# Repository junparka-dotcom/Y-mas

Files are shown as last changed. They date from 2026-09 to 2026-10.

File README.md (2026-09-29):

# Y-mas — 병실 침대 낙상 감지 / 환자 상태 모니터링 플랫폼

낙상을 "감지"하는 것을 넘어 **낙상 전 위험을 예측(pre-fall)** 하고, 같은
센서 인프라 위에 욕창 예방 자세 분류 등 임상 모니터링을 얹는 **풀 베드
솔루션**을 지향하는 프로젝트입니다.

이 저장소는 검증된 v17 Colab 노트북을 **버전 관리 가능한 모듈 구조**로
재구성한 것입니다. 노트북이 곧 코드였던 기존 방식에서 벗어나, 이 래포가
코드의 단일 진실 소스이고 Colab/GPU 환경은 이 래포를 clone 해 학습만
돌리는 실행기 역할을 합니다.

---

## 시스템 개요 (2-Tier)

| 단계 | 역할 | 구성 |
|---|---|---|
| **Tier 1** | 상시 감시 · 무게중심(COG) 편향 감지 | 로드셀 4채널 → HX711 → ESP32, 80Hz |
| **Tier 2** | 정밀 판정 · 낙상 확정 | ToF 카메라 → YOLO11n-pose → depth 3D 리프팅 → **ST-GCN 기반 모델(이 래포)** |
| **Tier 3** | 알림 | 간호 스테이션 앱 (미구현) |

저비용·저연산 센서(Tier 1)가 24시간 감시하다 위험 신호가 잡히면 고연산
비전 AI(Tier 2)가 깨어나 판정하는 구조입니다. 이 래포는 **Tier 2 모델**을
다룹니다.

## 모델 (v17)

- ST-GCN + Adaptive Graph Adjacency + Multi-Scale TCN(커널 3/5/9)
  + Temporal Attention Pooling + Physics Features 10종 + Auxiliary Fall Head
- trainable 약 1.48M 파라미터 (state_dict 총합 1.50M, BN 버퍼 포함)
- 학습: Focal Loss(γ=1.5) + EMA + Mixup + SWA, 도메인 균형 체크포인트 선택
- 데이터: **NTU RGB+D 120 + ETRI-Activity3D** (둘 다 Kinect V2 계열)
- 배포: ONNX opset 18 → TensorRT FP16 (Jetson AGX Orin)

## 저장소 구조

```
ymas/
  skeleton.py    NTU 25관절 정의 / 뼈대 연결 / 클래스·특징 이름 (단일 진실 소스)
  preprocess.py  전처리 불변식 (normalize_seq, physics_features, to_streams ...)
  config.py      Config + 피험자 분할 + 라벨 정의
  dataset.py     캐시 로드/병합, YmasDataset, DataLoader
  model.py       YmasNet, STGCNBlock, FocalLoss, EMA
  train.py       학습 루프 (EMA/SWA/도메인 균형 선택)
  evaluate.py    진단 + 임계값 스윕 + precision 우선 선택 + Holdout
  export.py      ONNX 내보내기
scripts/
  train_baseline.py   학습 진입점 (--config 로 실험 config 지정)
  diagnose_fa.py      오경보 해부 진단 (도메인/피험자/P(Fall) 분포)
  export_onnx.py      체크포인트 → ONNX
configs/
  v17_baseline.yaml   v13 그리드서치 확정 하이퍼파라미터 (재현 베이스라인)
  v18_aug.yaml        augmentation 강화 실험 (일반화 개선)
edge/                 Jetson Tier 2 실시간 추론 (ymas_realtime_ir.py, C++ 브리지, 캘리브레이션)
integration/          Tier 1 ↔ Tier 2 통합 (ymas_integrated.py, tier1_receiver)
firmware/             ESP32 Tier 1 펌웨어 (.ino)
hardware/             레일 플랫폼 CAD (OpenSCAD 소스 + STL + 프린트 가이드)
docs/
  handover.md         프로젝트 인수인계 (맥락 / 확정사항 / 폐기선택지 / 교훈)
  reference/          부품목록·종합정리 PDF (참고자료)
notebooks/
  colab_train.ipynb   Colab 실행 진입점 (git clone → import ymas)
```

## 학습 실행 (Colab / GPU)

```bash
git clone https://github.com/junparka-dotcom/Y-mas.git
cd Y-mas
pip install -r requirements.txt

python scripts/train_baseline.py \
  --ntu  /content/drive/MyDrive/.../ntu_ymas_v15_T64.npz \
  --etri /content/drive/MyDrive/.../etri_ymas_v15_T64.npz \
  --out  /content/drive/MyDrive/.../ckpt/ymas_v17_repro.pt
```

데이터 캐시(`*_v15_T64.npz`)는 Drive 에 보관하며 래포에는 커밋하지 않습니다
(`.gitignore`). 캐시가 있으면 원본 NTU/ETRI zip(수십 GB) 파싱이 불필요합니다.

## 개발 원칙 (인수인계 교훈)

1. **임계값은 precision≥0.95 게이트를 먼저 걸고 그 안에서 recall 최대화.**
   순서를 뒤집으면(“오경보 0 먼저”) 확률 절벽에서 recall 이 붕괴한다
   (실제 v16 에서 0.988 → 0.06).
2. **계산했다고 반영된 게 아니다.** SWA·평가·저장까지 반드시 검증한다.
3. 치수·스펙은 데이터시트/실물로 확인한다 (추측 금지).
4. Python 래퍼가 막히면 검증된 네이티브 경로로 내려간다.
5. **불변식:** `normalize_seq`, `physics_features`, `to_streams`, `pmean/pstd`
   는 학습·추론 코드에서 완전히 동일해야 한다.

자세한 배경은 [`docs/handover.md`](docs/handover.md) 참고.

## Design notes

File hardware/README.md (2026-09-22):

# Y-mas Tier 1 — 레일 플랫폼 CAD 파일

2026-08-18 설계분을 대화 기록에서 복원한 것입니다.

## 복원 검증

원본 생성 당시의 OpenSCAD `echo` 출력과 이번 재생성 출력이 일치합니다.

| 항목 | 원본(2026-08-18) | 현재(개선 반영) |
|---|---|---|
| 패드 | 200x50x6 / 단상 5 | + 하면 4점 지지 발 12x2.5 (전체 Z 13.5) |
| 브래킷→**어댑터** | 90x60x6 | **80x80x12** (PDF 확정치, 로드셀 40mm 대응 오프셋) |
| 램프 세그먼트 | 108.229mm, 0→29→58→87 | **115.694mm, 0→31→62→93** + 다웰 결합 |
| 데크 높이 | 87mm | **93mm** (어댑터 12mm 도입) |
| MCU 박스 | 미복구 | **복원** 80x60x30 (ESP32 55x26x13 실측 반영) |

> **개선 이력:** 계측 안정성/조립성 개선으로 아래가 바뀌었습니다.
> - 패드: 하면 전면접촉 → **4점 지지 발**(바닥 요철에도 영점 안정)
> - 브래킷 → **어댑터 플레이트(80×80×12)**: 로드셀 40mm 대응 + 자유단 체결홀이
>   바퀴 슬롯을 관통하지 않도록 레일 체결점을 오프셋. **오프셋 30mm는 임의값**이라
>   실측 확정 필요(MEASUREMENTS_TODO C). 두께 12mm로 굽힘강성도 확보.
> - 크래들: V홈을 **바퀴 지름 기반 파라메트릭**으로 정리 + 실측 강제 assert
> - 램프: 세그먼트 접합면에 **다웰 핀/구멍**(밀림 방지). 데크 93mm라 세그 115.7mm
> - MCU 박스: `mcu_enclosure.scad` **신규 복원**(base/lid), ESP32 실측 55×26×13 반영
> - 펌웨어: 빈 상태 **자동 영점 보정(auto-tare)**로 PETG 크리프 드리프트 대응

## 포함 파일

### 소스 (.scad) — 치수 수정은 여기서
```
rail_spec.scad             공용 파라미터  ← 실측값은 여기만 고치면 전체 연동
wheel_cradle.scad          바퀴 크래들
rail_loadcell_mount.scad   패드 + 어댑터 (part="pad" / "bracket")
rail_ramp_segment.scad     램프 분할 (seg=0/1/2)
wheel_chock.scad           고임목
mcu_enclosure.scad         중앙 MCU 박스 (part="base" / "lid")
rail_system.scad           전체 조립 뷰 (아래 '미복구' 참고)
```

### 출력용 (.stl)
```
rail_pad.stl          바닥 패드 + 로드셀 고정단 단상        x4
rail_adapter.stl      로드셀 자유단 ↔ 레일 어댑터(80x80x12) x4
wheel_cradle.stl      얕은 V 크래들                         x4
wheel_chock.stl       고임목                                x8
rail_ramp_seg0/1/2    램프 3분할                            각 x2
mcu_box_base.stl      중앙 MCU 박스 본체                    x1
mcu_box_lid.stl       중앙 MCU 박스 뚜껑                    x1
hx711_box_base.stl    HX711 박스 본체                       x4
hx711_box_lid.stl     HX711 박스 뚜껑                       x4
```

## 인클로저 (복원 완료)

`hx711_enclosure.scad` (HX711 박스 34x24x16) / `mcu_enclosure.scad` (MCU 박스
80x60x30, ESP32 55x26x13 실측 반영) **둘 다 복원 완료**. 각각 `part="base"`/`"lid"`.
`rail_system.scad` 전체 조립 뷰도 이제 정상 렌더됩니다(데크 93 / 램프 347 / 레일 2100).

공통 규격: 벽 두께 2~2.5mm, 모서리 필렛 R1.5~2, 볼트+육각너트 트랩 관통 체결.
HX711 박스는 유닛당 1개 = 4개, MCU 박스는 중앙 1개.

## STL 재생성

```bash
openscad -D 'part="pad"'     -o rail_pad.stl      rail_loadcell_mount.scad
openscad -D 'part="bracket"' -o rail_adapter.stl  rail_loadcell_mount.scad
openscad                     -o wheel_cradle.stl  wheel_cradle.scad
openscad                     -o wheel_chock.stl   wheel_chock.scad
for i in 0 1 2; do openscad -D "seg=$i" -o rail_ramp_seg$i.stl rail_ramp_segment.scad; done
openscad -D 'part="base"'    -o mcu_box_base.stl    mcu_enclosure.scad
openscad -D 'part="lid"'     -o mcu_box_lid.stl     mcu_enclosure.scad
openscad -D 'part="base"'    -o hx711_box_base.stl  hx711_enclosure.scad
openscad -D 'part="lid"'     -o hx711_box_lid.stl   hx711_enclosure.scad
```

또는 배치 출력용 plate 재생성: `python3 make_plates.py`

## 실측 후 수정할 파라미터 (rail_spec.scad)

```
wheel_d=60; wheel_thk=22;   // 바퀴 지름/두께 — 캘리퍼스 실측 필수
CASTER_PITCH = 1700;        // 앞뒤 캐스터 간격 — COG_X 계산에 직결
CRADLE_depth = 9;           // V홈 깊이 — 실물 굴림 테스트 필요
```
`rail_system.scad`의 `rail_gap = 560`(좌우 캐스터 간격)도 COG_Y에 직결됩니다.

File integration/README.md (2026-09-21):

# integration/ — Tier 1 ↔ Tier 2 통합

ESP32(Tier 1, 하중/COG) 가 UDP 로 ALERT 를 보내면 Jetson(Tier 2, 비전) 이
`threading.Event` 로 깨어나 낙상을 확정하는 2-Tier 연동.

## 파일

| 파일 | 역할 |
|---|---|
| `ymas_integrated.py` | Tier 1(하중) + Tier 2(비전) 통합 실행. ESP32 UDP 수신 → 인터럽트 → 비전 스레드 → ST-GCN → MQTT 알람. `--sim --mock-camera` 로 하드웨어 없이 테스트 가능 |
| `ymas_tier1_receiver.py` | Tier 1 수신부. ESP32 하중/COG 수신(Serial/UDP) + 모니터링/로깅 + ALERT 시 Tier 2 기동. 시뮬레이터 내장 |
| `collect_ymas_jetson.sh` | Jetson 자산 수집 스크립트 |

## 하드웨어 없이 Tier 1 검증하기 (시뮬레이터)

ESP32·센서·납땜 없이 `ymas_tier1_receiver.py` 의 내장 시뮬레이터(`--sim`)로
Tier 1 로직 전체(3-Path 감지 / 낙상 vs 정상기상 구분 / ALERT → Tier 2 기동)를
검증할 수 있다.

```bash
# 낙상: ALERT 발생 + Tier 2 기상 + 반응시간 측정
python3 ymas_tier1_receiver.py --sim --scenario fall --quiet

# 정상 기상: ALERT 가 뜨지 않아야 정상 (오탐 없음)
python3 ymas_tier1_receiver.py --sim --scenario exit --quiet

# 그 외 시나리오: edge(가장자리 접근), normal(안정)
python3 ymas_tier1_receiver.py --sim --scenario edge
```

### 검증 완료 (2026-09, 시뮬레이터)
- **낙상(fall):** 낙하 개시 → ALERT 까지 **반응 시간 166ms** (사유
  FASTPATH_WEIGHT_DROP). 인수인계 목표 141~181ms 범위 내. Tier 2 기상 시
  인터럽트 직전 200프레임 하중 이력 확보 확인.
- **정상 기상(exit):** ALERT/인터럽트 미발생 → 침대에서 내려가는 동작을
  낙상으로 오탐하지 않음 (낙상 0.6s 급락 vs 정상기상 2.5s 완만 감소를 dW/dt 로 구분).
- **파싱 정합성:** 펌웨어 출력 포맷(YMAS 16필드 / YMAS_ALERT 8필드)과
  수신부 파서 일치 확인.
- 결론: **Tier 1 소프트웨어 로직은 검증 완료.** 남은 것은 실물(ESP32 +
  HX711·로드셀 납땜) 검증 — 하드웨어 준비 후 펌웨어 업로드 → rate(80Hz 확인)
  → tare → calall → 실측.

## [!] 버전 주의 — ymas_integrated.py 는 구버전(v13) 기준

`ymas_integrated.py` 는 헤더가 **ST-GCN v13 / `ymas_v13.onnx`** 기준으로
작성되어 있다. 현재 확정 모델은 **v21**(배포 th=0.77, physics 10)이므로,
end-to-end 통합 실증 전에 아래를 v21 기준으로 맞춰야 한다:
- ONNX 경로 (`ymas_v13.onnx` → `ymas_v21_model_dropout` 기반 ONNX)
- physics 차원 (v13 은 8, v17+ 은 10)
- PMEAN/PSTD, 임계값 (TH_FALL 0.77)

`ymas_tier1_receiver.py` 의 Tier 2 연동 주석은 이미 th_fall=0.77(v21)로
맞춰져 있고, `edge/ymas_realtime_ir.py` 는 physics 10 / 전처리 불변식이
학습 코드와 동일하므로, 통합 시 edge 쪽 전처리·상수를 기준으로 통일 권장.

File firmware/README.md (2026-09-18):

# firmware/ — ESP32 Tier 1 펌웨어

## `ymas_tier1_firmware.ino`

- **타겟:** keyestudio ESP32-WROOM-32D (KS0413)
- **센서:** CAS BCA-100L ×4 → HX711 ×4
- **역할:** 4채널 하중 수집 → COG 산출 → 3-Path 감지 판정 → LAN UDP 로 Jetson 전송

### 저지연 설계 (v2)

1. HX711 **80Hz 모드** — 샘플 간격 100ms → 12.5ms (**RATE 핀 하드웨어 개조 필수**)
2. 중앙값 필터 — 이동평균 대비 지연 절반, 스파이크 제거 우수
3. 예측 감지 — 이탈도 변화율로 임계 도달 전 선행 알람
4. Fast Path — 체중 급락 시 확정 절차 생략
5. LAN UDP 전송 — 전송 지연 1ms 미만

목표 반응 시간: **0.15 ~ 0.30초**

### COG 산출 (플랫폼 저울 원리)

```
COG_X = CASTER_PITCH × (RL+RR)/total
COG_Y = RAIL_GAP    × (FR+RR)/total
```

`CASTER_PITCH`, `RAIL_GAP` 은 실측 미확정 가정값(1700mm / 560mm). 실물 침대
측정 후 펌웨어 상수를 확정해야 COG 정확도가 보장된다.

### 빌드

Arduino IDE 또는 arduino-cli 로 ESP32 보드에 업로드. HX711 라이브러리 필요.
업로드 전 반드시 HX711 4개의 RATE 핀 개조(트레이스 컷 + 15번 핀 VCC 점퍼)를
완료할 것 — 개조 없이는 10Hz 에 묶여 지연이 1.5초대로 올라간다.

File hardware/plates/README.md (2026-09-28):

# H2D 배치 출력용 Plate (재료별 분리)

밤부랩 H2D 베드(**350×320mm**)에 부품을 묶어 배치한 plate입니다.
**재료별로 폴더가 나뉘어** 있어 PETG는 PETG끼리, PLA는 PLA끼리 출력합니다.
각 plate는 **STL + 3MF** 둘 다 제공합니다.

- **3MF 권장** — Bambu Studio 네이티브 포맷. 오브젝트 분리·배치·재료 지정이 STL보다 매끄러움.
- STL도 동일 내용(멀티오브젝트). 다른 슬라이서 호환용.
- 어느 쪽이든 열면 각 부품이 **개별 오브젝트로 인식**되어 재배치·개별 삭제 가능.

## 폴더 구조

```
plates/
├── petg/   ← 하중 경로 부품 (PETG로 출력)
│   ├── plate_pads.stl / .3mf
│   └── plate_adapter_cradle.stl / .3mf
└── pla/    ← 비하중 부품 (PLA로 출력)
    ├── plate_chock_ramp.stl / .3mf
    └── plate_enclosures.stl / .3mf
```

## 구성 (총 28개 부품 → 4판)

### 🔵 PETG — 하중 경로 (`petg/`)

| Plate | 담긴 부품 | 개수 | 풋프린트 |
|---|---|---|---|
| `plate_pads` | rail_pad | 4 | 200×218mm |
| `plate_adapter_cradle` | rail_adapter ×4 + wheel_cradle ×4 | 8 | 282×258mm |

### 🟢 PLA — 비하중 (`pla/`)

| Plate | 담긴 부품 | 개수 | 풋프린트 |
|---|---|---|---|
| `plate_chock_ramp` | wheel_chock ×8 + rail_ramp seg0/1/2 각 ×2 | 14 | 307×234mm |
| `plate_enclosures` | mcu_box(base+lid) + hx711_box(base×4+lid×4) | 10 | 166×120mm |
| `plate_chock_enclosures` | wheel_chock ×8 + mcu_box + hx711_box(×4) | 18 | 214×234mm |

> **`plate_chock_enclosures`** 는 램프를 지금 안 뽑을 때 쓰는 **통합 판**입니다.
> 휠초크 + 전자부 인클로저를 한 번에 출력 (램프 제외). 램프는 부피가 커서
> 나중에 따로 뽑거나 합판/각목 대체. plate_chock_ramp / plate_enclosures 와는
> 부품이 겹치므로 **셋 중 필요한 조합만** 골라 쓰세요.

모든 판이 베드(350×320) 안에 들어가며, 부품 간 겹침 0, 간격 6mm·가장자리 여백 8mm로 배치했습니다.
생성기(`make_plates.py`)가 **재료 혼합을 assert로 차단**하므로 판에 다른 재료가 섞이지 않습니다.

## 재료 분류 근거

| 부품 | 재료 | 이유 |
|---|---|---|
| rail_pad, rail_adapter, wheel_cradle | **PETG** | 침대 하중이 상시 통과하는 하중 경로 — PLA 크리프로 영점 드리프트 |
| wheel_chock | PLA | 측면 걸림 역할, 지속 압축 없음 |
| rail_ramp seg0/1/2 | PLA | 하중 경로와 분리된 독립 부품, 진입 시 순간 하중만 |
| mcu_box, hx711_box | PLA | 전자부 보호용, 하중 없음 |

## 슬라이서 인필 — 판/오브젝트별로 다르게

| Plate | 재료 | 인필 | 벽 | 이유 |
|---|---|---|---|---|
| `plate_pads` | PETG | **60%+** | 5겹 | 하중 경로. 크리프 방지 |
| `plate_adapter_cradle` | PETG | adapter **60%+** / cradle 40% | 5 / 4겹 | 어댑터는 하중 경로, cradle은 바퀴 하중+마찰 |
| `plate_chock_ramp` | PLA | chock 30% / **ramp 10~15%** | 3겹 | 램프는 하중 분리 부품 |
| `plate_enclosures` | PLA | 20~30% | 3겹 | 전자부 보호용 |

## ⚠️ plate_chock_ramp 는 시간이 오래 걸립니다

램프 3종(seg0/1/2 각 2개)은 솔리드 부피가 커서(seg2 하나만 ~580cm³) 전체 출력량의 대부분을 차지합니다. 권장:

- 램프 인필을 **10~15%**로 낮추고 상/하면 3겹 (강도 충분 — 진입 시 순간 하중만)
- 램프는 정밀도가 필요 없는 15° 경사 형상이라 **합판/각목으로 대체 제작**도 가능
- 시제품 검증 단계면 chock만 먼저 뽑고 램프는 나중에

## 재생성

개별 STL(`../stl/`)이 바뀌면 다시 생성:

```bash
cd hardware
python3 make_plates.py     # plates/{petg,pla}/ 에 STL + 3MF 재생성
```

> 3MF 생성에는 `trimesh` + `networkx` 가 필요합니다(`pip install trimesh networkx`).
> 없으면 STL만 생성되고 안내 메시지가 출력됩니다.

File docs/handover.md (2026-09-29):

# Y-mas 프로젝트 인수인계

> 이 문서는 프로젝트 맥락(설계 근거·확정 사항·폐기 선택지·교훈)을 보존한다.
> 새 작업을 시작하기 전에 반드시 읽고, 여기 적힌 확정 사항과 폐기 선택지
> 안에서 논의할 것.

## 프로젝트 정체성

- **Y-mas** — 병실 침대 낙상 감지 시스템. 궁극 목표는 낙상 "감지"가 아니라
  **낙상 전 위험 예측(pre-fall)**, 나아가 침대 환자 상태 모니터링 **풀 베드
  솔루션**.
- 대학 경진대회 출품작 (AI반도체 전공 학부생).

## 시스템 아키텍처

| 단계 | 역할 | 구성 |
|---|---|---|
| Tier 1 | 상시 감시 · COG 편향 감지 | 로드셀 4 → HX711 4 → ESP32, 80Hz, UDP 트리거 |
| Tier 2 | 정밀 판정 | Femto W(ToF) → IR 주입력 → YOLO11n-pose → depth 3D 리프팅 → ST-GCN(v17) |
| Tier 3 | 알림 | 간호 스테이션 앱 (미구현) |

Tier 1 이 UDP 트리거를 보내면 Tier 2 가 `threading.Event` 로 깨어난다.

## 확정 사항 (변경 제안 불필요)

### 하드웨어
- 엣지 보드: **NVIDIA Jetson AGX Orin 64GB 개발자 키트** (재플래시 완료 2026-09-29)
  - JetPack **6.2.3** (Jetson Linux), CUDA **12.6** (nvcc V12.6.68), Docker 29.8.1
  - Jetson 계정 `ymas`, **IP 192.168.0.9** (`ssh ymas@192.168.0.9`) — ESP32 펌웨어 JETSON_IP 와 일치
  - eMMC 57GB(35GB 여유) — Docker/데이터셋 많이 쓰면 M.2 NVMe 추가 필요
  - 기존 Orin Nano Super 8GB 에서 교체. CUDA/메모리/전력이 커서 추론 여유 대폭↑
    (아래 v17 성능 수치는 Nano Super 기준 하한선 — AGX Orin 에서는 더 빠름)
  - ⚠️ 전력: 평소 50W(`nvpmodel -m 3`), 학습/벤치 시만 MAXN(`nvpmodel -m 0` + `jetson_clocks`)
  - ⚠️ PyTorch 는 `pip install torch`(CPU판) 금지 → JetPack 6.2.3용 NVIDIA wheel/컨테이너 사용
  - ⚠️ Ubuntu 24.04 업그레이드 금지(JetPack 6 = 22.04 기준, CUDA/드라이버 깨짐)
  - 상세 재플래시 절차: `docs/jetson_reflash_2026-09-29.md`
- 카메라: Orbbec Femto W (ToF, Depth/IR) — **IR 이 주 입력** (소등 시 RGB 검출 0)
- MCU: ESP32-WROOM-32D
- 로드셀: CAS BCA-100L ×4 (150×35×**40**mm, 100kg, 2mV/V, IP65)
- 증폭: HX711 ×4, SCK 공유 결선, **RATE 핀 개조로 80Hz** (필수)
- 구조: 알루미늄 프로파일 30×60mm 레일 플랫폼

### Tier 2 모델 (v17)
- ST-GCN + Adaptive Graph + Multi-Scale TCN(3/5/9) + Temporal Attention Pool
  + Physics 10종 + Aux Fall Head
- trainable ~1.48M (state_dict 총합 1.50M, BN 버퍼 포함)
- Focal(γ=1.5), EMA(0.9999), Mixup(0.4), SWA, dropout=0.45, aux_weight=0.15,
  label_smooth=0.15
- 성능(문서 기준): th=0.75 에서 Holdout NTU recall 0.976, ETRI 0.988,
  오경보 79건(P39/P40 집중)
- 배포: ONNX opset 18 → TensorRT FP16, 평균 ≈2ms / ≈478 qps
- ONNX I/O: `skeleton[B,9,64,25]`, `physics[B,10]` → `logits[B,3]`

### 카메라 파이프라인
- IR/Depth 동일 물리 센서 공유 → Align 불필요
- `pyorbbecsdk` 는 0 채운 depth 만 반환 → C++ SDK v1.10.37 브릿지로 우회
  (Unix 도메인 소켓 스트리밍)
- zone 4점 캘리브레이션, 복합 판정(zone 이탈 AND tilt≥45° → Fall),
  EMA 스무딩(α=0.4) + 신뢰도 게이트(0.3)

## 폐기된 선택지 (다시 제안 금지)

### 데이터셋 — 전부 도메인 갭으로 실패
| 데이터셋 | 실패 원인 |
|---|---|
| Kaggle UR Fall | Depth 누락 |
| UP-Fall 3D | MediaPipe 33관절 → NTU 25관절 변환 시 성능 붕괴 |
| PKU-MMD v2 | 좌표계 불일치, precision 0.76 → 0.52 |
| FUKinect-Fall | Kinect V1 노이즈 전 백분위 3배, 필터 불가 |

**결론: 같은 센서 계열(Kinect V2 포맷) 데이터만 학습 투입 가능
→ 현재 NTU RGB+D 120 + ETRI-Activity3D 만 사용.**

### 기타 폐기
- 개별 캐스터 유닛 방식 → 레일 플랫폼으로 전환
- Nuitrack / K4A Body Tracking SDK (Femto W 미지원) → YOLO11n-pose + depth 리프팅
- 자탭 나사 → 볼트+육각너트 트랩 관통 체결
- 더 무거운 스켈레톤 모델(2s-AGCN, MS-G3D, CTR-GCN, ST-TR) — 엣지 실시간성 ·
  데이터 규모 대비 과적합 위험

## 뼈아팠던 교훈

1. **임계값은 precision 게이트(≥0.95)를 먼저 걸고 그 안에서 recall 최대화.**
   "오경보 0 먼저" 규칙이 확률 절벽 끝(th=0.95)을 골라 NTU recall 0.988 → 0.06 붕괴.
2. **계산했다고 반영된 게 아니다.** SWA 가중치를 계산만 하고 저장·평가하지
   않은 버그가 로그상 이상 없이 v13~v15 를 통과.
3. **치수는 데이터시트로 확인.** 로드셀 두께 22mm 가정 → 실제 40mm 로 기구 전면 재설계.
4. **Python 래퍼가 막히면 검증된 네이티브 경로로.** pyorbbecsdk → C++ 브릿지.
5. **불변식:** `normalize_seq`, `physics_features`, `to_streams`, `pmean/pstd` 는
   학습·추론에서 완전히 동일해야 한다.

## 데이터 현황 (캐시 실측)

| 캐시 | 샘플 | 클래스 분포 | 피험자 |
|---|---|---|---|
| `ntu_ymas_v15_T64.npz` (495MB) | 27,679 | Normal 20,114 / Risk 6,618 / Fall 947 | 54 |
| `etri_ymas_v15_T64.npz` (125MB) | 7,002 | Normal 5,168 / Risk 0 / Fall 1,834 (전부 A053) | 60 |

병합 34,681 → Train 18,771 / Val 9,803 / Holdout 6,107.

- pmean = [3.3124, 3.1606, 0.3925, 1.1291, 33.0563, 20.9063, 0.4188, 6.1961, 2.4740, 0.1158]
- pstd  = [7.8035, 5.5430, 0.5598, 0.5744, 27.6783, 22.7895, 0.5998, 9.3450, 0.6205, 0.1538]

### 데이터가 드러낸 약점 (개선 실험 표적)
1. **극심한 Fall 불균형** (Fall 2,781 vs Normal 25,282 ≈ 1:9) + 동적 낙상
   궤적(NTU A043)이 947개뿐. ETRI Fall 1,834 는 "쓰러지는 순간이 없는 정적 자세".
2. **Risk 는 NTU 단독** (ETRI 0) → 도메인 지름길 학습 위험.
3. 오경보가 특정 피험자(P39/P40)에 집중 → 하드 네거티브 문제.

## 미해결 상태

1. **실환경 도메인 갭 (가장 큼)** — v17 은 Kinect/NTU 만 학습해 Femto W 노이즈를
   본 적 없음. 정상 자세에서 P(Fall) 0.75~0.80. 근본 해결은 현 파이프라인으로
   **실데이터 수집 후 파인튜닝** (현재 카메라 수집 불가 상태).
2. 실측 미확정 치수 (캐스터 피치 1700mm, 레일 간격 560mm 등 — COG 식 직결 가정값).
3. Femto W USB 끊김 시 220V 재인가 필요 (무인 운용 리스크).
4. 미구현: Tier 3 앱, Tier 1 실물 제작 · end-to-end 통합, 풀 베드 확장.

## 로드맵

- **Phase 0 (완료)** — v17 노트북을 래포 모듈로 재구성 + 재현 베이스라인 확립.
  Holdout NTU recall 0.9762 / ETRI 0.9875 / 오경보 79 재현 성공 (th=0.75).
- **Phase 1 (v18 완료)** — 캐시 기반 정직한 개선 실험.
  - 진단 결과 하드 네거티브 재가중은 폐기(Train non-Fall 16,905개 중
    P(Fall)>=0.75 단 2건 → 재가중 대상 없음, 순수 일반화 실패로 판명).
  - **augmentation 강화(v18)** 채택: 다축 회전(rot_y 0.35 + rot_xz 0.12)
    + 관절 드롭아웃(p=0.3, frac=0.1). 확신 오답(P>=0.90) 18→7건 감소.
  - **배포 임계값 th=0.78 확정**: NTU 동적 낙상 recall 0.9762 완전 유지하며
    Holdout 오경보 79→67 (-15%). th>=0.79 부터 NTU recall 절벽 붕괴.
  - 관련: configs/v18_aug.yaml, scripts/analyze_threshold.py, scripts/diagnose_fa.py
  - **[폐기] 관절 드롭아웃 강도 튜닝 — v18(frac=0.10)이 스위트 스팟으로 확정:**
    - v19 (frac 0.05, 완화): NTU recall 0.9762→0.9643 하락. **드롭아웃 줄이지 말 것.**
    - v20 (frac 0.15, 강화): 최적 오경보 68(v18은 67), NTU recall 유지 th 범위 더
      좁음. v18 대비 개선 없음. **드롭아웃 더 키우지 말 것.**
    - 결론: 양쪽으로 벗어나면 나빠짐 → joint_dropout_frac=0.10 고정. 이 축은 수렴.
    - (configs/v19_finetune.yaml, configs/v20_strong_dropout.yaml, 둘 다 미병합)
- **Phase 1 최종 (v21 채택):** model dropout 0.45→0.50 (특징 레벨 정규화)이
  일반화를 더 밀어 **미답 피험자(P39/P40)의 동적 낙상까지 완벽 감지**.
  - **배포 th=0.77 확정.** Holdout NTU 동적 낙상 recall **1.000**(84/84),
    전체 오경보 70. th 0.70~0.77 구간에서 NTU recall 1.000 유지, 0.78부터 하락.
  - SWA 가 EMA best 를 이겨 채택됨 (정규화 강화로 SWA 가 더 안정적 해에 수렴).
  - v17→v21 개선: NTU 낙상 recall 0.9762→**1.000**, 전체 오경보 79→70.
  - 판정 근거: 낙상 감지 시스템에서 놓친 낙상(FN)이 오경보(FP)보다 치명적 →
    낙상 2개 추가 감지 vs 오경보 3건 증가는 임상적으로 남는 거래.
  - 관련: configs/v21_model_dropout.yaml. 체크포인트 ymas_v21_model_dropout.pt
- **Phase 1 이후 후보** — 관절 드롭아웃·model dropout 축 모두 탐색 완료.
  캐시 고정·데이터 유일(NTU 947 동적 낙상) 상황에서 모델 쪽 여지는 거의 소진.
  진짜 남은 병목은 실데이터(Phase 2, 카메라 필요)와 배포 정비(AGX Orin).
- **Phase 2 (하드웨어 준비 후)** — Femto W 실데이터 수집 → 파인튜닝으로 도메인 갭 해소.
  (현재 카메라 수집 불가 상태라 보류.)

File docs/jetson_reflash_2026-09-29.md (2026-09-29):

# Jetson AGX Orin 재플래시 작업 정리

**작업일:** 2026-09-29
잠겨 있던 Jetson 초기화 → JetPack 6.2.3 설치 → 노트북 파티션 정리

## 1. 작업 요약

이전 사용자가 쓰던 **Jetson AGX Orin 64GB 개발자 키트**가 비밀번호로 잠겨 있어,
듀얼부팅 노트북(Ubuntu 22.04)의 SDK Manager로 OS를 통째로 재설치(재플래시).
플래시 후 CUDA·개발 도구까지 설치, 작업 공간으로 쓰던 옛 Ubuntu 파티션(p8)은
삭제해 Windows D: 드라이브에 합쳤다.

| 항목 | 결과 |
|---|---|
| Jetson 기기 | Jetson AGX Orin 64GB Developer Kit (64GB eMMC 5.1) |
| 설치 소프트웨어 | JetPack 6.2.3 (Jetson Linux), CUDA 12.6 (nvcc V12.6.68) |
| Jetson 계정 | 사용자명 `ymas` (Pre-Config로 플래시 전 지정) |
| **Jetson IP** | **192.168.0.9** (`ssh ymas@192.168.0.9`) |
| 호스트 PC | 듀얼부팅 노트북, Ubuntu 22.04.5 LTS, x86_64, SDK Manager 2.4.1 |

> **ESP32 펌웨어 연동:** `firmware/ymas_tier1_firmware.ino` 의 `JETSON_IP` 를
> 192.168.0.9 로 맞춰 두었다(UDP 5005). 네트워크가 바뀌면 이 값도 함께 갱신할 것.

## 2. 재플래시가 필요했던 이유

Jetson OS 비밀번호는 OS 안(`/etc/shadow`)에 저장되므로, 모르면 OS 재설치가
가장 확실. Recovery 모드에서는 OS 부팅 전 부트롬이 USB로 명령을 받으므로
잠긴 로그인 화면과 무관하게 저장장치 전체를 덮어쓸 수 있다.

## 3. 사전 확인 (노트북, Ubuntu 터미널)

| 항목 | 명령 | 결과 |
|---|---|---|
| Ubuntu 버전 | `lsb_release -a` | 22.04.5 LTS (jammy) |
| CPU 구조 | `uname -m` | x86_64 |
| 여유 공간 | `df -h /` | / 에 61GB 여유 |

> SDK Manager는 Windows/WSL/VM/Mac에서 플래시가 불안정 → **실제 Ubuntu 부팅** 필수.

## 4. 진행 순서

### 4-1. 작업 폴더 준비 (p8 파티션)
마운트 안 된 ext4 파티션(`nvme0n1p8`, 144.9GB)을 SDK Manager 다운로드용으로 사용.
```
sudo mkdir -p /mnt/p8
sudo mount /dev/nvme0n1p8 /mnt/p8
sudo mkdir /mnt/p8/nvidia
sudo chown $USER:$USER /mnt/p8/nvidia
```

### 4-2. SDK Manager 설치
NVIDIA 개발자 사이트에서 Ubuntu(.deb x86_64) 다운로드 후:
```
cd ~/Downloads
sudo apt install ./sdkmanager_*.deb
sdkmanager
```

### 4-3. SDK Manager 설정
| 단계 | 설정 |
|---|---|
| Step 01 Target HW | 기본값 AGX Thor → **Jetson AGX Orin [64GB developer kit version]** 로 변경 |
| Step 01 SDK Version | **JetPack 6.2.3**, Direct Flash (JetPack 7.x는 Thor용이라 해당 없음) |
| Step 01 Additional SDKs | DeepStream, Holoscan **체크 해제** |
| Step 02 경로 | Download: `/mnt/p8/nvidia/sdkm_downloads`, Install: `/mnt/p8/nvidia/nvidia_sdk` |
| Step 02 체크박스 | 약관 동의, "Download now. Install later" 체크 안 함 |
| Flash 창 | OEM Config: **Pre-Config**(사용자명/비번 지정), Storage: **EMMC** |

### 4-4. Recovery 모드 진입 (AGX Orin 개발자 키트)
1. 전원 어댑터 연결한 채, Jetson 끈 상태(전원 LED 꺼짐)
2. USB-C ↔ USB-A 케이블로 노트북과 **직접** 연결 (허브 금지)
3. **Force Recovery 버튼(가운데)** 누른 채 유지
4. 그 상태에서 **Power 버튼**을 눌렀다 뗀다
5. 2~3초 뒤 Force Recovery 버튼을 뗀다 (화면 꺼져 있는 게 정상)
6. 확인: `lsusb` 에 `NVIDIA Corp. APX` 계열이 보이면 성공

### 4-5. 플래시 및 컴포넌트 설치
- Flash 약 20~40분. 진행 중 USB 케이블/노트북 재부팅 금지(`/mnt/p8` 마운트 유지)
- 플래시 후 Jetson 재부팅 시 SDK Manager가 USB 가상 네트워크(`192.168.55.1`)로
  접속해 Runtime Components(CUDA Runtime, Container Runtime 등) 설치
- 접속 확인: `ping -c 3 192.168.55.1` (응답 3/3)
- 최종: **INSTALLATION COMPLETED SUCCESSFULLY**

## 5. 발생한 문제와 해결

| 문제 | 원인 | 해결 |
|---|---|---|
| Target HW가 AGX Thor로 표시 | Jetson 미연결로 자동감지 실패, 기본값 표시 | 연결 후 수동으로 Orin [64GB dev kit] 지정 |
| "running in normal mode" 메시지 | Recovery 아닌 일반 부팅으로 인식 | 기기 종류만 선택하고 진행, 실제 Recovery는 Flash 단계에서 |
| "Verifying System Readiness" 실패 (apt exitCode 100) | 옛 설치의 `cdrom:` 저장소 항목이 apt update 실패시킴 | `sources.list` 의 `deb cdrom:` 줄 주석 처리 후 Retry |

```
sudo cp /etc/apt/sources.list /etc/apt/sources.list.bak
sudo sed -i '/^deb cdrom:/s/^/# /' /etc/apt/sources.list
sudo apt-get update   # 에러 없이 Done이면 해결
```

## 6. Jetson 설치 결과 확인

| 항목 | 결과 |
|---|---|
| JetPack | `nvidia-jetpack`, `-dev`, `-runtime` 모두 6.2.3+b81 |
| CUDA | `nvcc --version` → release 12.6, V12.6.68 |
| 저장공간 | `/dev/mmcblk0p1` (eMMC) 57GB 중 35GB 여유 |
| 메모리 | 62,828MB 인식 (64GB) |
| Docker | 29.8.1, docker 그룹에 사용자 추가 |
| 네트워크 | **192.168.0.9** (`ssh ymas@192.168.0.9`) |
| 대기 온도 | CPU ~46°C, GPU ~41°C (`tegrastats`) |
| 전력 모드 | 기본 50W → `nvpmodel -m 0`(MAXN) + `jetson_clocks` 로 확인 |
| 추가 설치 | Terminator, Firefox, ibus-hangul, jtop |

## 7. 노트북 파티션 정리 (p8 삭제 → D: 확장)

| 파티션 | 크기 | 종류 | 비고 |
|---|---|---|---|
| p1 | 260MB | EFI | 부팅 (그대로) |
| p3 | 480GB | NTFS | Windows C: (그대로) |
| p9 | 85GB | ext4 | 현재 Ubuntu / (삭제 금지) |
| p5 | 199.6→344GB | NTFS | Back Up (D:), p8 합쳐 확장 |
| p8 | 145GB | ext4 | 옛 Ubuntu, **삭제됨** |
| p4/p6/p7 | 921MB/19GB/1GB | — | 삼성 복구용 (그대로) |

순서: `umount /mnt/p8` → `/etc/fstab` 에 p8 없음 확인 → Windows 디스크 관리에서
145GB 삭제 → D: 확장 → Ubuntu `sudo update-grub`. 결과: D: 344GB(273GB 가용),
Windows/Ubuntu 듀얼부팅 정상.

## 8. 앞으로 주의할 점

- **비밀번호는 따로 기록**할 것 (이번 재플래시 원인이 분실).
- `do-release-upgrade` 로 **Ubuntu 24.04 업그레이드 금지** — JetPack 6은 22.04 기준,
  CUDA/드라이버 깨짐.
- `jetson_clocks` 는 재부팅하면 풀림. MAXN은 발열·전력이 높으니 학습/벤치 때만.
  평소: `sudo jetson_clocks --restore` + `sudo nvpmodel -m 3` (50W).
- Docker 그룹 변경은 **로그아웃 후 재로그인** 해야 적용.
- **PyTorch: `pip install torch`(CPU판) 금지** → JetPack 6.2.3용 NVIDIA wheel/컨테이너.
- eMMC 여유 35GB — Docker/데이터셋 많이 쓰면 부족. M.2 Key M 슬롯에 NVMe 추가.
- 재플래시 시 `/mnt/p8` 없으므로 다운로드 폴더를 Ubuntu `/`(약 61GB)로 지정,
  Jetson Linux만 선택하면 공간 충분.

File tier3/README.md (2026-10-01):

# tier3/ — 간호 스테이션 낙상 알림 웹앱 (Tier 3)

Tier 2(비전) 또는 Tier 1(하중)이 낙상/위험을 감지하면, 간호 스테이션
브라우저 대시보드에 **실시간으로 경보**를 띄운다. 2-Tier 감지 파이프라인의
마지막 단계(알림)를 담당한다.

```
[Tier 2 비전 / Tier 1 하중 / mock] --POST /ingest 또는 WS /ws/ingest-->
      [FastAPI 서버] --WS /ws/dashboard--> [브라우저 대시보드(들)]
```

## 구성

| 파일 | 역할 |
|---|---|
| `schema.py` | 이벤트 데이터 규격 `FallEvent` (Tier 2/Tier 1 필드 통합) + `Severity` |
| `server/app.py` | FastAPI 서버 — 이벤트 수신, 대시보드 broadcast, 확인(ack), 이력, 정적 서빙 |
| `static/index.html` | 대시보드 — 침대별 상태 카드, 낙상 시 전체화면 경보(빨강+소리), 확인 버튼, 이벤트 로그 |
| `mock_tier2.py` | 하드웨어 없이 검증용 — 낙상/정상 시나리오를 서버로 전송 |
| `requirements-tier3.txt` | 서버 의존성 (fastapi, uvicorn) |

## 실행

### 1) 서버 기동
```bash
pip install -r tier3/requirements-tier3.txt
cd tier3/server
python -m uvicorn app:app --host 0.0.0.0 --port 8000
```
브라우저에서 **http://localhost:8000** 접속 → 대시보드.

### 2) 하드웨어 없이 낙상 알림 테스트 (다른 터미널)
```bash
# 낙상 시나리오: 정상 → 주의 → 위험 → 낙상 (대시보드에 빨간 경보가 떠야 함)
python tier3/mock_tier2.py --scenario fall --bed 301-A

# 정상 시나리오: 낙상 경보가 뜨지 않아야 정상
python tier3/mock_tier2.py --scenario normal --bed 301-A

# 여러 침대 혼합
python tier3/mock_tier2.py --scenario multi
```

## 이벤트 스키마 (`FallEvent`)

Tier 2 실물(`edge/ymas_realtime_ir.py`)과 Tier 1 펌웨어가 실제로 가진 값에
맞춰 정의했다. 필수는 `bed_id`, `severity`뿐이고 나머지는 있는 값만 채운다.

| 필드 | 출처 | 설명 |
|---|---|---|
| `bed_id`, `severity` | 공통 | 침대 ID / NORMAL·CAUTION·DANGER·FALL |
| `reason` | Tier1/2 | 트리거 사유 (FASTPATH_WEIGHT_DROP 등) |
| `p_normal/p_risk/p_fall` | Tier2 | ST-GCN 3클래스 확률 |
| `tilt_final`, `zone_status`, `exit_tag` | Tier2 | 몸통 기울기 / zone 이탈 / EXIT 태그 |
| `total_kg`, `cog_x`, `cog_y`, `edge_ratio` | Tier1 | 총중량 / 무게중심 / 이탈도 |
| `event_id`, `acknowledged`, `ack_ts` | 서버 | 서버 부여 ID / 확인 여부·시각 |

## 실제 Tier 2 연결 (완료 ✅)

`edge/ymas_realtime_ir.py` 가 낙상 확정(`pred_class == 2`) 시 `FallEvent` 를
서버 `/ingest` 로 POST 하도록 **연동 완료**. 비차단(데몬 스레드+2초 타임아웃) +
쿨다운(기본 10초)으로 실시간 루프에 영향 없이 동작한다.

환경변수로 제어(미설정이면 Tier 2 단독 동작):
- `YMAS_TIER3_URL`  — 알림 서버 주소 (예: `http://localhost:8000`)
- `YMAS_BED_ID`     — 침대 ID (기본 `301-A`)
- `YMAS_TIER3_COOLDOWN` — 낙상 알림 최소 간격 초 (기본 10)

실행(수동):
```bash
cd ~/Y-mas/edge && YMAS_TIER3_URL=http://localhost:8000 python3 ymas_realtime_ir.py
```
systemd 로 함께 운영: `edge/systemd/`(ymas-tier3.service) + `install_services.sh`.
자세한 절차는 `edge/DEPLOY_AGX_ORIN.md` 9단계 참고.

## 검증 완료 (로컬 E2E, 하드웨어 없음)

FastAPI TestClient 로 전체 파이프라인 검증:
- 대시보드 WS 연결 → 스냅샷 수신
- 정상/낙상 이벤트 ingest → 대시보드 실시간 수신 (P(Fall), 사유 포함)
- 간호사 확인(ack) → 전 대시보드 broadcast
- 이력/침대 상태 API, 여분 필드 무시(스키마 견고성)
- mock fall 시나리오: NORMAL→CAUTION→DANGER→FALL 전이 확인

> 참고: `schema.py`는 Python 3.9 호환(`Optional[...]` 사용). 서버는 3.9+ 동작.

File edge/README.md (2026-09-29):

# edge/ — Jetson Tier 2 실시간 추론

Orbbec Femto W(ToF) → IR/Depth 캡처 → YOLO11n-pose → depth 3D 리프팅 →
NTU 25관절 매핑 → ST-GCN(v17) 낙상 판정. Jetson AGX Orin 에서 구동.

## 파일

| 파일 | 역할 |
|---|---|
| `ymas_realtime_ir.py` | **주 실행 파일.** IR 주입력 실시간 통합 추론 (포즈→뎁스 리프팅→조인트 매핑→v17→zone 필터). `normalize_seq`/`physics_features`/`to_streams`/PMEAN/PSTD 가 학습 코드와 동일 |
| `ymas_realtime.py` | 이전 버전(RGB-D 경로). IR 경로로 대체됨 — 참고용 |
| `bed_calibrate.py` | IR 화면에서 침대 4모서리 클릭 → `bed_region.json` 생성 |
| `bed_region.json` | 침대 zone 폴리곤 (픽셀 좌표). zone 이탈 판정에 사용 |
| `watchdog.sh` | 브리지 감시·자동 재시작 (무개입 복구) |
| `bridges/` | C++ depth/IR 캡처 브리지 (Unix 도메인 소켓 스트리밍) + 파이썬 클라이언트/진단 |
| `tests/` | ONNX/TensorRT 엔진 검증, 카메라 스트림 테스트 |

## bridges/

`pyorbbecsdk` 가 0 으로 채운 depth 만 반환하는 문제 때문에 C++ SDK(v1.10.37)로
직접 캡처해 Unix 도메인 소켓(`/tmp/ymas_depth.sock`)으로 파이썬에 스트리밍한다.

| 파일 | 역할 |
|---|---|
| `ir_depth_bridge.cpp` | **주 브리지.** IR+Depth 동시 캡처, `select()` 재접속 지원 |
| `ir_bridge.cpp` / `depth_bridge.cpp` / `rgbd_bridge.cpp` | 단일 스트림/실험용 브리지 |
| `*_client.py`, `rgbd_diag*.py` | 브리지 수신 클라이언트 및 진단 |

## 불변식 주의

`ymas_realtime_ir.py` 의 전처리 함수와 PMEAN/PSTD 는 학습 코드
(`ymas/preprocess.py`, 체크포인트의 pmean/pstd)와 **완전히 동일해야 한다.**
모델을 v18 이상으로 갱신하면 이 파일의 PMEAN/PSTD/TH_FALL 도 함께 맞출 것.

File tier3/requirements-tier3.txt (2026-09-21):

# Tier 3 간호 스테이션 알림 서버 의존성
fastapi>=0.110
uvicorn[standard]>=0.29
# 클라이언트(mock, 대시보드)는 표준 라이브러리만 사용 (추가 설치 불필요)

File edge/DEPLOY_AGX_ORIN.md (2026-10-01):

# Tier 2 배포 가이드 — Jetson AGX Orin

ST-GCN v17 낙상 모델을 AGX Orin(JetPack 6.2.3, CUDA 12.6, TensorRT 10.3)에 배포하는 절차.
모델 파일은 래포에 없으므로(gitignore) **Colab/Drive에서 가져온다.**

> 실측(2026-10-01): 엔진 벤치 ~1ms/추론(≈988 qps), 실시간 파이프라인 FPS 30
> (YOLO11n-pose+ST-GCN 모두 CPU onnxruntime), FALL ALERT 까지 end-to-end 검증 완료.
> GPU(TensorRT) 추론 전환은 추후 최적화 과제.

> 이 문서의 명령은 **모두 AGX Orin 에서** 실행한다(`ssh ymas@192.168.0.9`).
> 모델 I/O: `skeleton[1,9,64,25]`, `physics[1,10]` → `logits[1,3]` (T=64, V=25, n_phys=10)

---

## 0. 준비 — 코드/모델 가져오기

### 0-1. 래포 클론(또는 최신화)
```bash
cd ~
git clone https://github.com/junparka-dotcom/Y-mas.git   # 최초 1회
# 이미 있으면:  cd ~/Y-mas && git pull
cd ~/Y-mas
```

### 0-2. 모델 파일 가져오기 (Drive → Jetson)
Colab 학습 산출물은 Google Drive 에 있다. 필요한 파일:
- `ymas_v17.onnx` (+ `ymas_v17.onnx.data` external weight — **반드시 같이**)
- `validation_samples_v17.npz` (엔진 검증용, Colab CELL 에서 생성)

Drive 에서 받는 방법(택1):
```bash
# (A) 브라우저로 Drive 에서 다운로드 후 scp/USB 로 옮기기
# (B) gdown 사용 (파일 공유링크 ID 필요)
pip install --user gdown
gdown 'https://drive.google.com/uc?id=<FILE_ID>' -O ymas_v17.onnx
gdown 'https://drive.google.com/uc?id=<FILE_ID>' -O ymas_v17.onnx.data
gdown 'https://drive.google.com/uc?id=<FILE_ID>' -O validation_samples_v17.npz
```
작업 폴더 예: `~/Y-mas/edge/` 에 세 파일을 둔다.

---

## 1. 환경 점검
```bash
# JetPack / CUDA / TensorRT 버전
dpkg -l | grep nvidia-jetpack | head -1
nvcc --version
dpkg -l | grep -i tensorrt | grep -i libnvinfer-bin || /usr/src/tensorrt/bin/trtexec --help | head -1
python3 -c "import tensorrt as trt; print('TensorRT', trt.__version__)"

# 전력 최대 모드(빌드/벤치 시에만)
sudo nvpmodel -m 0 && sudo jetson_clocks
```
기대: JetPack 6.2.3, CUDA 12.6, TensorRT 10.x.

---

## 2. TensorRT FP16 엔진 빌드
```bash
cd ~/Y-mas/edge
/usr/src/tensorrt/bin/trtexec \
  --onnx=ymas_v17.onnx \
  --saveEngine=ymas_v17_fp16.engine \
  --fp16 \
  --shapes=skeleton:1x9x64x25,physics:1x10
```
- 성공 시 `ymas_v17_fp16.engine` 생성 + "PASSED" 로그.
- `.onnx.data` 가 같은 폴더에 없으면 weight 로드 실패 → 0-2 확인.

---

## 3. 엔진 검증 (PyTorch 로짓과 비교)
```bash
# 검증 스크립트는 cuda-python(from cuda import cudart) 필요. 재플래시 후엔 없음.
# ⚠️ cuda-python 13.x 는 API 가 cuda.bindings 로 이동해 import 가 깨진다.
#    시스템 CUDA 12.6 에 맞춰 12.x 를 설치할 것:
pip install --user "cuda-python>=12.6,<13"

cd ~/Y-mas/edge/tests
# 검증 스크립트는 ymas_v17_fp16.engine / validation_samples_v17.npz 를 현재 폴더에서 찾음
cp ../ymas_v17_fp16.engine .
cp ../validation_samples_v17.npz .
python3 validate_engine.py
```
기대 출력: 예측 클래스 전체 일치(YES), 평균 max|diff| 작음(FP16 반올림 오차 범위).
> ⚠️ npz 의 physics 차원이 8이면 현재 모델(n_phys=10)과 불일치 → Colab 에서
> n_phys=10 기준으로 `validation_samples_v17.npz` 를 재생성할 것.

---

## 4. 성능 벤치 (추론 속도)
```bash
# 엔진만으로 순수 추론 처리량 측정
/usr/src/tensorrt/bin/trtexec \
  --loadEngine=ymas_v17_fp16.engine \
  --shapes=skeleton:1x9x64x25,physics:1x10 \
  --iterations=1000 --avgRuns=100
```
- `mean`(ms/inference), `throughput`(qps) 확인.
- 기준(Nano Super): v17 ≈2ms / ≈478 qps. **AGX Orin 은 이보다 빠를 것.**

---

## 5. Orbbec C++ 브리지 빌드 (카메라)
> 카메라(Femto W) 연결 후 진행. 하드웨어 없으면 4단계까지만.

### 5-1. 카메라 인식 확인
```bash
lsusb | grep -i -E "orbbec|2bc5"   # 2bc5:0638 Orbbec Femto W Camera 가 보여야 함
```

### 5-2. Orbbec SDK v1.10.37 (arm64) 설치
재플래시 후에는 SDK 가 없다. GitHub 릴리스에서 **linux_arm64** zip 을 받는다:
```bash
mkdir -p ~/orbbec_sdk && cd ~/orbbec_sdk
wget -O OrbbecSDK_arm64.zip "https://github.com/orbbec/OrbbecSDK/releases/download/v1.10.37/OrbbecSDK_C_C%2B%2B_v1.10.37_20260707_3f75820_linux_arm64_release.zip"
sudo apt-get install -y unzip   # 없으면
unzip -o OrbbecSDK_arm64.zip
```
> ⚠️ 압축 해제 후 include/lib 는 최상위가 아니라 **`OrbbecSDK_v1.10.37/SDK/`** 하위에 있다.
> - 헤더: `OrbbecSDK_v1.10.37/SDK/include/libobsensor/ObSensor.hpp`
> - 라이브러리: `OrbbecSDK_v1.10.37/SDK/lib/libOrbbecSDK.so`

### 5-3. udev 규칙 설치 (USB 권한 — 필수)
안 하면 브리지가 카메라를 못 연다. 설치 후 **카메라 USB 를 뽑았다 다시 꽂는다.**
```bash
cd ~/orbbec_sdk/OrbbecSDK_v1.10.37/Script
sudo bash install_udev_rules.sh
sudo udevadm control --reload-rules && sudo udevadm trigger
```

### 5-4. 브리지 컴파일
```bash
cd ~/Y-mas/edge/bridges
SDK=~/orbbec_sdk/OrbbecSDK_v1.10.37/SDK
g++ -std=c++17 ir_depth_bridge.cpp -o ir_depth_bridge \
  -I"$SDK/include" \
  -L"$SDK/lib" -lOrbbecSDK -lpthread \
  -Wl,-rpath,"$SDK/lib"          # ← rpath 필수(런타임에 .so 를 찾게)
# 실행: IR+Depth 캡처 → /tmp/ymas_irdepth.sock 스트리밍
./ir_depth_bridge
```
성공하면 `depth intrinsics: fx=... fy=...` 에 실제 숫자가 찍히고
`waiting for python client...` 로 대기한다.
> ⚠️ 소켓 경로는 **`/tmp/ymas_irdepth.sock`** 이다(실제 브리지/클라이언트 코드 기준).
> - `pyorbbecsdk`(파이썬 바인딩)는 0 채운 depth 만 반환하므로 **C++ 브리지 필수.**
> - `watchdog.sh` 로 브리지 자동 재시작 감시 가능.

---

## 6. 실시간 통합 추론

### 6-1. 파이썬 의존성 (재플래시 후 필요)
```bash
pip install --user onnxruntime          # CPU 판. Jetson GPU 가속은 별도 wheel 필요(아래 참고)
pip install --user "numpy<2"            # ⚠️ 시스템 cv2 4.8 은 numpy 1.x 로 빌드됨. numpy 2.x 면 cv2 import 깨짐
# cv2 는 JetPack 기본 opencv(4.8) 사용. import 되는지 확인:
python3 -c "import onnxruntime, cv2, numpy; print('deps OK', cv2.__version__, numpy.__version__)"
```
> 🚫 **Orin 에서 `pip install ultralytics` 금지.** 범용 torch 2.x + `nvidia-*-cu13` 뭉치(수 GB)를
> 끌고 와 JetPack(CUDA 12.6) 환경을 오염시키고 eMMC 를 치먹으며 numpy 를 2.x 로 올려
> cv2/`cuda-python` 을 깨뜨린다. YOLO ONNX 는 **Colab 에서 export** 한다(아래 6-2).

### 6-2. YOLO11n-pose ONNX 확보 (Colab)
`edge/yolo11n-pose.onnx` 는 래포에 없다(gitignore). `notebooks/ymas_yolo11n_pose_export.ipynb`
를 Colab(무료 T4)에서 실행해 export → Drive 저장 → Orin 으로 옮긴다:
```bash
mv ~/Downloads/yolo11n-pose.onnx ~/Y-mas/edge/
```
> export 는 `imgsz=320`(코드 `YOLO_SIZE` 와 일치), `opset=12`.
> 출력 shape 은 `(1, 56, 2100)` (imgsz 320 기준; 640 이면 8400). 실시간 코드 파싱과 호환.

### 6-3. 필요한 모델 파일 (모두 `~/Y-mas/edge/`)
- `yolo11n-pose.onnx` (Colab export, 6-2)
- `ymas_v17.onnx` (+ `.onnx.data`, 0-2)
- `bed_region.json` (아래 캘리브레이션 또는 래포 동봉본)

### 6-4. 실행 (터미널 2개)
```bash
# 터미널 A — 브리지 (카메라 캡처, 먼저)
cd ~/Y-mas/edge/bridges && ./ir_depth_bridge

# 터미널 B — 실시간 추론
cd ~/Y-mas/edge
python3 bed_calibrate.py       # 침대 zone 4점 캘리브레이션(최초 1회) → bed_region.json
python3 ymas_realtime_ir.py    # 브리지가 /tmp/ymas_irdepth.sock 스트리밍 중이어야 함
```
- 모델/로그 경로는 스크립트(`edge/`) 기준으로 자동 해석된다(하드코딩 제거됨).
  필요 시 `YMAS_POSE_ONNX`/`YMAS_FALL_ONNX`/`YMAS_BED_JSON`/`YMAS_LOG_DIR` 로 override.
- `cv2.imshow` GUI 창이 뜬다 → Orin 로컬 디스플레이 필요(순수 SSH 면 표시 안 됨).
- `ymas_realtime_ir.py` 의 PMEAN/PSTD/전처리는 학습 코드와 **동일해야** 함(불변식).
- 모델 갱신 시 PMEAN/PSTD/TH_FALL 도 함께 맞출 것.
- 정상 판정 로그 예:
  `buf=15 zone=in tilt_final=51.0 [EXIT+TILT] P(Fall)=.. -> Fall *** FALL ALERT ***`

---

## 6-B. (최적화) GPU 추론 — TensorRT 백엔드

기본은 YOLO11n-pose / ST-GCN 을 **CPU onnxruntime** 으로 돌린다(30fps 나옴).
아래처럼 **TensorRT 엔진**을 만들어 두면 `ymas_realtime_ir.py` 가 자동으로 GPU 를 쓴다
(엔진 없으면 onnxruntime 으로 폴백, `YMAS_FORCE_ONNX=1` 이면 강제 CPU).

```bash
cd ~/Y-mas/edge
# (빌드 중엔 MAXN 권장)  sudo nvpmodel -m 0 && sudo jetson_clocks

# YOLO11n-pose ONNX → FP16 엔진 (입력 고정 1x3x320x320 → --shapes 불필요)
/usr/src/tensorrt/bin/trtexec \
  --onnx=yolo11n-pose.onnx \
  --saveEngine=yolo11n-pose_fp16.engine --fp16
# ST-GCN 엔진은 2단계에서 이미 빌드함(ymas_v17_fp16.engine)

# 엔진 텐서 이름 확인용(YOLO: images/output0, STGCN: skeleton,physics/logits)
python3 -c "import tensorrt as trt; l=trt.Logger();
import sys; f=open('yolo11n-pose_fp16.engine','rb'); e=trt.Runtime(l).deserialize_cuda_engine(f.read());
print([(e.get_tensor_name(i), e.get_tensor_mode(e.get_tensor_name(i))) for i in range(e.num_io_tensors)])"
```

- 실행은 6-4 와 동일(`python3 ymas_realtime_ir.py`). 시작 로그에
  `pose backend: TensorRT` / `fall backend: TensorRT` 가 뜨면 GPU 사용 중.
- 헬퍼: `edge/trt_infer.py`(cuda-python 기반, onnxruntime.run 유사 규약).
- 실측(50W 모드): FPS 30 유지, `tegrastats` 상 CPU 코어 대부분 <20%, GR3D(GPU) 활성.
  YOLO 를 GPU 로 넘겨 CPU 여유가 크게 확보됨(멀티카메라/추가로직 여지).
- FP16 이라 확률값은 소수점 미세차 가능하나 판정 클래스는 CPU 와 동일해야 함.
  비교하려면 `YMAS_FORCE_ONNX=1 python3 ymas_realtime_ir.py` 로 CPU 강제.

---

## 7. 마치고 — 전력 원복
```bash
sudo jetson_clocks --restore
sudo nvpmodel -m 3      # 평소 50W 모드
```

---

## 8. 무인 운영 — systemd 부팅 자동실행/자동복구

24시간 무인 낙상 감지를 위해 브리지+추론을 systemd 서비스로 등록한다.
부팅 시 자동 시작 + 프로세스가 죽으면 자동 재시작(`Restart=always`).

### 8-1. 헤드리스 모드
서비스는 GUI(디스플레이)가 없으므로 실시간 스크립트가 헤드리스로 동작해야 한다.
`ymas_realtime_ir.py` 는 `YMAS_HEADLESS=1`(또는 `DISPLAY` 미설정)이면 자동으로
`cv2.imshow`/렌더를 생략하고 **로그/경보만** 남긴다(30초 하트비트 로그 포함).
GUI 로 보고 싶으면 그냥 데스크톱 터미널에서 직접 실행하면 된다.

### 8-2. 설치 (서비스 등록 + 자동시작)
```bash
cd ~/Y-mas/edge/systemd
sudo bash install_services.sh
```
스크립트가 하는 일: 유닛 파일을 `/etc/systemd/system/` 로 복사 →
`daemon-reload` → `enable`(부팅 자동시작) → `start`.

두 서비스:
| 서비스 | 역할 | 의존 |
|---|---|---|
| `ymas-bridge.service` | Orbbec C++ 브리지(카메라 캡처) | - |
| `ymas-realtime.service` | 헤드리스 추론(낙상 판정) | bridge 를 Requires/After |

### 8-3. 상태/로그 확인
```bash
systemctl status ymas-bridge ymas-realtime
journalctl -u ymas-realtime -f    # 실시간 판정/하트비트 로그
journalctl -u ymas-bridge -f      # 브리지(카메라) 로그
```

### 8-4. 재시작/중지/제거
```bash
sudo systemctl restart ymas-realtime          # 추론만 재시작
sudo systemctl restart ymas-bridge            # 브리지 재시작(추론도 함께 영향)
sudo systemctl disable --now ymas-realtime ymas-bridge   # 자동시작 해제 + 중지
```

### 8-5. 부팅 자동실행 검증
```bash
sudo reboot
# 재부팅 후(로그인 없이도 떠 있어야 함):
systemctl is-active ymas-bridge ymas-realtime   # 둘 다 active
journalctl -u ymas-realtime -n 20               # 판정/하트비트 로그 확인
```

> 참고: `edge/watchdog.sh` 는 systemd 가 없는 환경용 폴백(브리지만 감시)이다.
> systemd 를 쓰면 8단계로 대체된다(브리지+추론 모두 감시/복구).
> GPU 엔진(6-B)이 있으면 서비스도 자동으로 TensorRT 를 쓴다.

---

## 9. Tier 3 연동 — 간호 스테이션 대시보드 알림

Tier 2(이 보드)가 낙상을 확정하면 Tier 3 알림 서버(`tier3/`)로 `FallEvent` 를
POST → 간호 스테이션 브라우저 대시보드에 **실시간 빨강 경보**가 뜬다.

```
[ymas_realtime_ir.py] --낙상 확정(POST /ingest)--> [Tier3 FastAPI :8000] --WS--> [대시보드 브라우저]
```

### 9-1. 동작 방식 (코드)
`ymas_realtime_ir.py` 는 `YMAS_TIER3_URL` 이 설정됐을 때만 낙상(`pred_class==2`)
시 알림을 보낸다. 미설정이면 Tier 2 단독 동작(기존과 동일).
- **비차단**: 별도 데몬 스레드 + 2초 타임아웃 → 서버가 느리거나 죽어도 추론은 계속
- **쿨다운**: `YMAS_TIER3_COOLDOWN`(기본 10초)로 FALL 알림 폭주 방지
- 환경변수: `YMAS_TIER3_URL`(예: `http://localhost:8000`), `YMAS_BED_ID`(기본 `301-A`)

### 9-2. 서버 의존성 설치
```bash
pip install --user -r ~/Y-mas/tier3/requirements-tier3.txt   # fastapi, uvicorn
```

### 9-3. systemd 로 함께 운영 (8단계에 포함됨)
`install_services.sh` 는 Tier3 서버(`ymas-tier3.service`)도 함께 설치하며,
`ymas-realtime.service` 에 `YMAS_TIER3_URL=http://localhost:8000` 이 설정돼 있다.
8단계 설치를 하면 bridge + tier3 + realtime 3개가 함께 뜬다.
```bash
cd ~/Y-mas/edge/systemd && sudo bash install_services.sh
# 대시보드:  http://localhost:8000  (오린 로컬) 또는 http://<오린IP>:8000 (간호 스테이션 PC)
journalctl -u ymas-realtime -f    # 낙상 시 [tier3] FALL 알림 전송 로그 확인
journalctl -u ymas-tier3 -f       # 서버 수신 로그
```

### 9-4. 수동 실행(테스트용, systemd 없이)
```bash
# 터미널 1: Tier3 서버
cd ~/Y-mas/tier3/server && python3 -m uvicorn app:app --host 0.0.0.0 --port 8000
# 터미널 2: 브리지
cd ~/Y-mas/edge/bridges && ./ir_depth_bridge
# 터미널 3: 실시간 추론 (Tier3 전송 켜기)
cd ~/Y-mas/edge && YMAS_TIER3_URL=http://localhost:8000 YMAS_BED_ID=301-A python3 ymas_realtime_ir.py
```
하드웨어 없이 대시보드만 먼저 보려면: `python3 ~/Y-mas/tier3/mock_tier2.py --scenario fall`

### 9-5. 서버를 별도 간호 스테이션 PC 에 둘 때
Tier3 서버를 다른 PC 에서 돌리면, `ymas-realtime.service` 의
`YMAS_TIER3_URL` 을 그 PC IP 로 바꾼다(예: `http://192.168.0.50:8000`).
서버는 `--host 0.0.0.0` 이라 같은 네트워크면 브라우저로 접속 가능.

---

## 트러블슈팅
| 증상 | 원인/해결 |
|---|---|
| trtexec weight 로드 실패 | `ymas_v17.onnx.data` 가 onnx 와 같은 폴더에 있어야 함 |
| `import tensorrt` 실패 | JetPack 기본 파이썬(python3) 사용. venv 면 `--system-site-packages` |
| PyTorch CPU만 됨 | `pip install torch` 금지 → JetPack 6.2.3용 NVIDIA wheel/컨테이너 |
| validate physics 차원 오류 | npz(physics=8) vs 모델(n_phys=10) → npz 재생성 |
| 엔진 로드 실패(버전) | 엔진은 빌드한 그 TensorRT 버전에서만 로드됨. Jetson 에서 직접 빌드할 것 |
| `from cuda import cudart` 실패 | cuda-python 13.x 는 `cuda.bindings` 로 이동. `pip install "cuda-python>=12.6,<13"` |
| `cv2` import 시 numpy 오류 | numpy 2.x ↔ 시스템 cv2 4.8(numpy 1.x 빌드) 충돌 → `pip uninstall numpy` 로 시스템 1.21 복귀 or `pip install "numpy<2"` |
| ultralytics 설치 후 환경 오염 | Orin 에서 설치 금지. torch/cu13 뭉치가 JetPack 오염 + cuda-python 깨짐. YOLO export 는 Colab 에서 |
| 브리지 컴파일 시 `ObSensor.hpp` 없음 | include 는 `SDK/include` 하위. `-I$SDK/include` 로 지정 |
| 브리지 실행 시 `.so` 못 찾음 | 컴파일에 `-Wl,-rpath,$SDK/lib` 추가 |
| 브리지 카메라 오픈 실패/권한 | udev 규칙 설치 후 USB 재삽입(5-3) |
| 실시간 `cv2.imshow` display 오류 | Orin 로컬 디스플레이 필요. 순수 SSH 면 GUI 표시 안 됨 |
| 모델 경로 못 찾음 | 경로 하드코딩 제거됨(스크립트 기준 자동). `YMAS_POSE_ONNX` 등 env 로 override 가능 |
| systemd 서비스가 GUI 오류로 죽음 | 서비스는 헤드리스여야 함. `YMAS_HEADLESS=1` 이 유닛에 설정돼 있음(8-1) |
| 서비스에서 cuda-python/onnxruntime 못 찾음 | pip `--user` 설치라 `HOME=/home/ymas` 가 유닛에 설정돼 `~/.local` 인식(8-2) |
| 서비스 계속 재시작 반복 | `journalctl -u ymas-realtime -n 50` 로 원인 확인. 모델/엔진 파일 존재 여부부터 |
| 재부팅 후 안 뜸 | `systemctl is-enabled ymas-bridge ymas-realtime` 확인. 아니면 `enable`(8-2) |
| 대시보드에 낙상 안 뜸 | realtime 로그에 `[tier3] FALL 알림 전송` 뜨는지 확인. 안 뜨면 `YMAS_TIER3_URL` 미설정 |
| `[tier3] 전송 실패` 로그 | Tier3 서버 미기동/방화벽. `journalctl -u ymas-tier3`, `curl localhost:8000/healthz` |
| ymas-tier3 안 뜸 | fastapi/uvicorn 미설치. `pip install --user -r ~/Y-mas/tier3/requirements-tier3.txt`(9-2) |
| 다른 PC 에서 대시보드 접속 안 됨 | 서버는 `0.0.0.0:8000`. 오린 방화벽/네트워크 확인, URL은 오린 IP(192.168.0.9) |

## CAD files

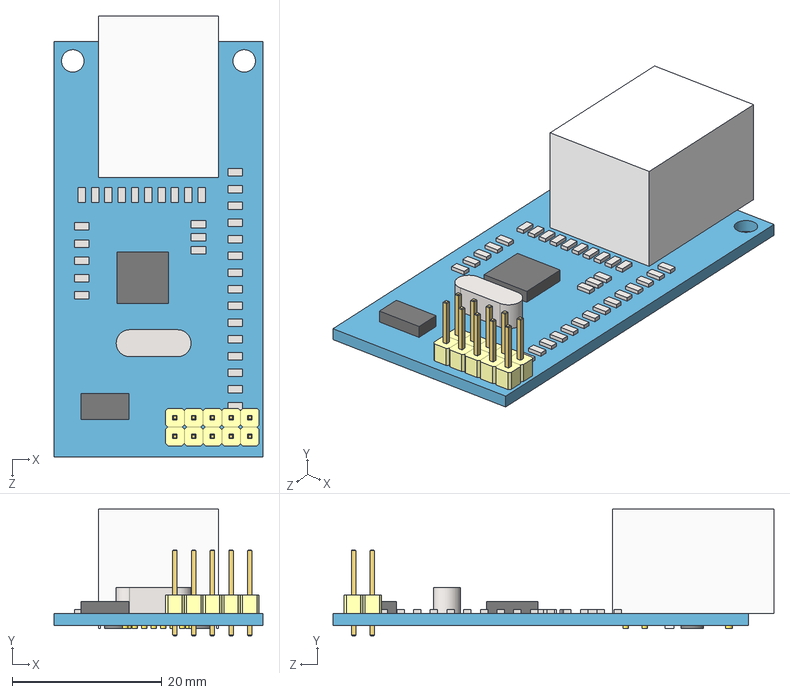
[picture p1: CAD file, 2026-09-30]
hardware/Assembly W5500 ethernet module.STEP
27.9 x 17.0 x 58.9 mm
Plate W5500 ethernet module
body.stp
contact.stp x 8
Pins W5500 ethernet module

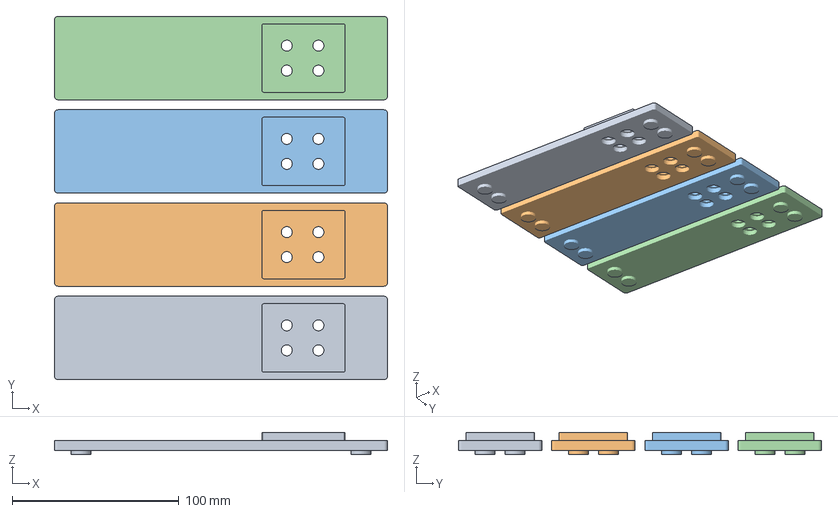
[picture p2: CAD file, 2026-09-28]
hardware/plates/petg/plate_pads.3mf
200.0 x 218.0 x 13.5 mm
rail_pad_0
rail_pad_1
rail_pad_2
rail_pad_3

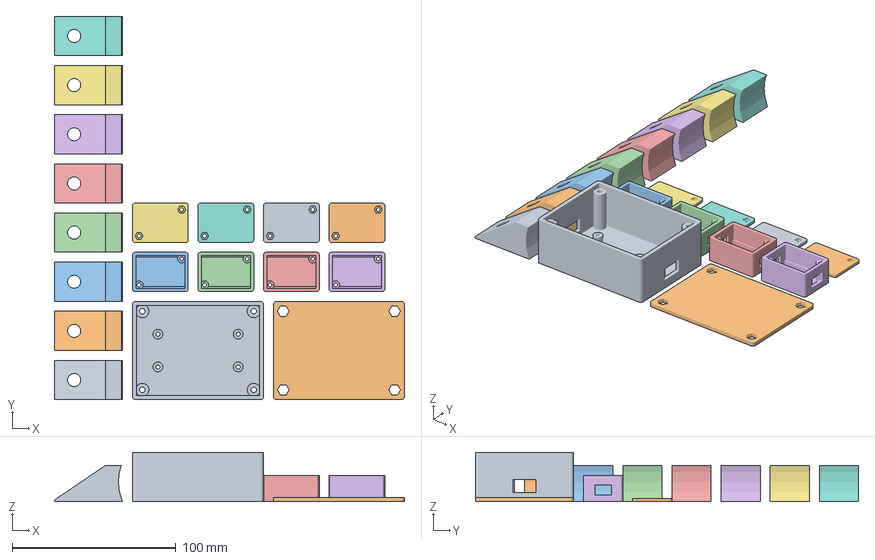
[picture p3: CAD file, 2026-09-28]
hardware/plates/pla/plate_chock_enclosures.3mf
213.6 x 234.0 x 30.0 mm
wheel_chock_0
wheel_chock_1
wheel_chock_2
wheel_chock_3
wheel_chock_4
wheel_chock_5
wheel_chock_6
wheel_chock_7
mcu_box_base_8
mcu_box_lid_9
hx711_box_base_10
hx711_box_base_11
hx711_box_base_12
hx711_box_base_13
hx711_box_lid_14
hx711_box_lid_15
hx711_box_lid_16
hx711_box_lid_17

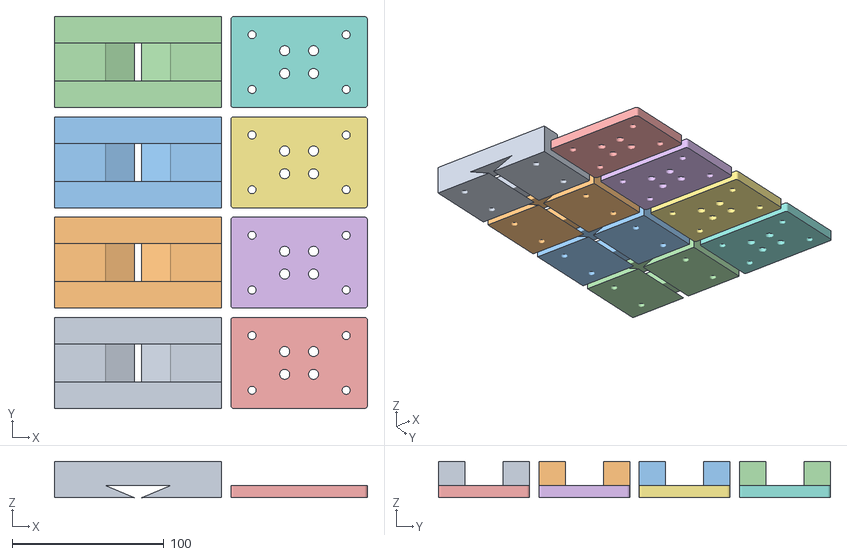
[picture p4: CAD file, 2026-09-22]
hardware/plates/plate2_bracket_cradle.stl
206.0 x 258.0 x 24.0
wheel_cradle_0
wheel_cradle_1
wheel_cradle_2
wheel_cradle_3
rail_bracket_4
rail_bracket_5
rail_bracket_6
rail_bracket_7

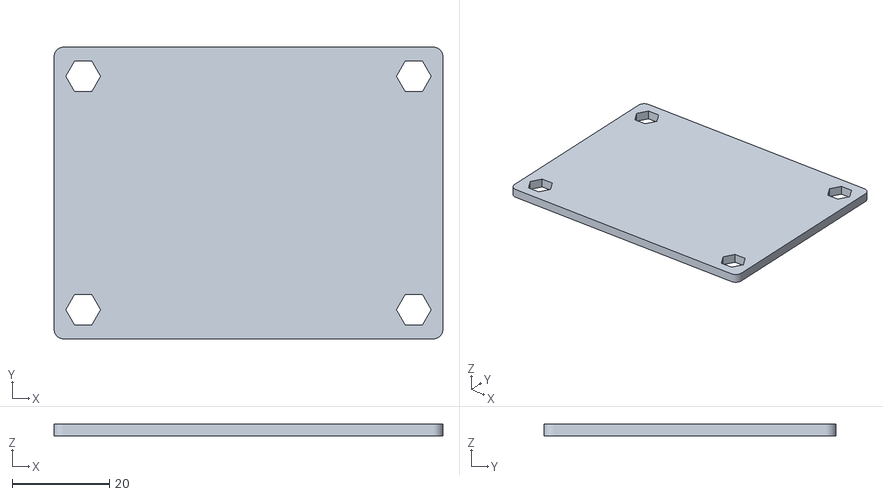
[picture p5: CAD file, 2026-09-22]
hardware/stl/mcu_box_lid.stl
80.0 x 60.0 x 2.50

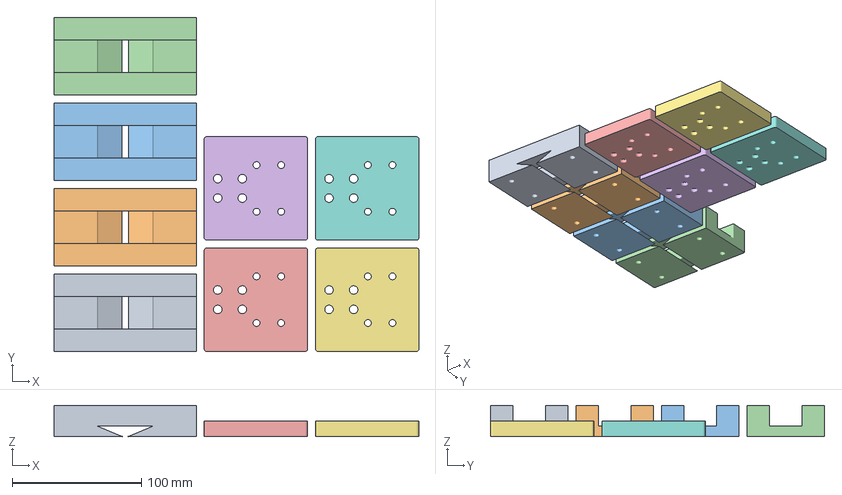
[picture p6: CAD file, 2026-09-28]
hardware/plates/petg/plate_adapter_cradle.3mf
282.0 x 258.0 x 24.0 mm
wheel_cradle_0
wheel_cradle_1
wheel_cradle_2
wheel_cradle_3
rail_adapter_4
rail_adapter_5
rail_adapter_6
rail_adapter_7

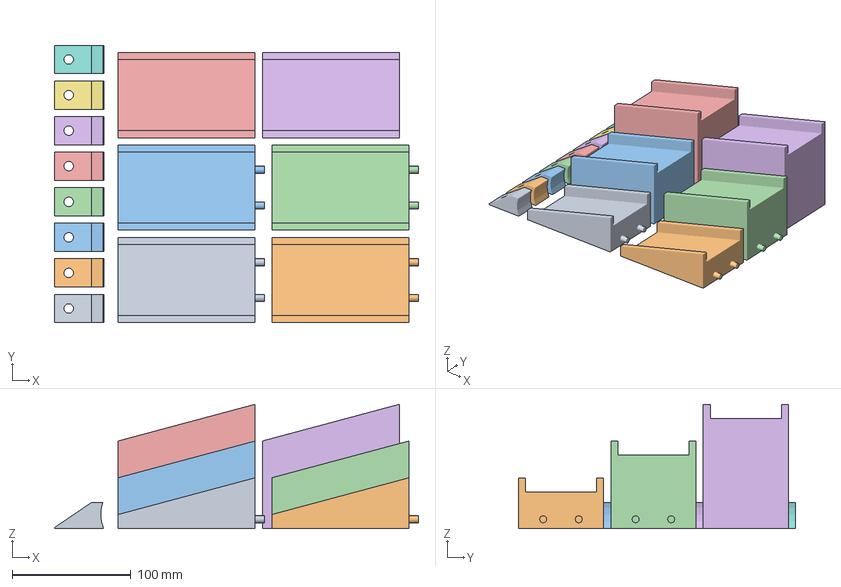
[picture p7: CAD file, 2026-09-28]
hardware/plates/pla/plate_chock_ramp.3mf
307.0 x 234.0 x 105.0 mm
wheel_chock_0
wheel_chock_1
wheel_chock_2
wheel_chock_3
wheel_chock_4
wheel_chock_5
wheel_chock_6
wheel_chock_7
rail_ramp_seg0_8
rail_ramp_seg0_9
rail_ramp_seg1_10
rail_ramp_seg1_11
rail_ramp_seg2_12
rail_ramp_seg2_13

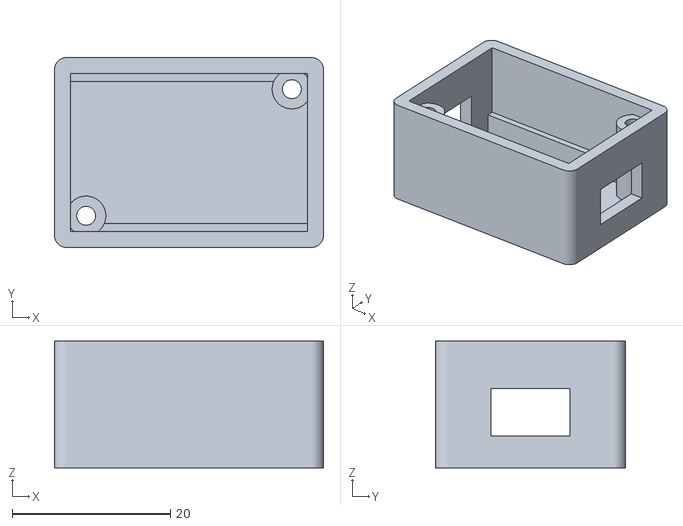
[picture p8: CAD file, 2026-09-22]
hardware/stl/hx711_box_base.stl
34.0 x 24.0 x 16.0

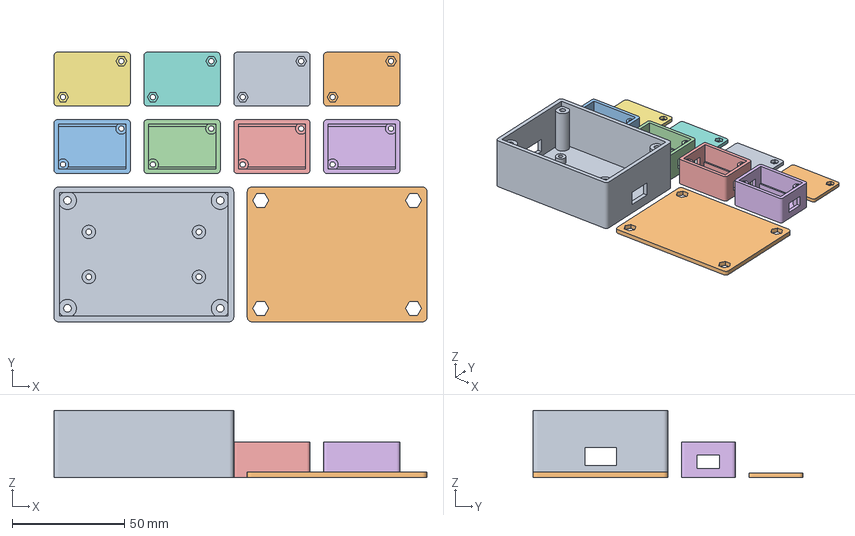
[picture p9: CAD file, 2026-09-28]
hardware/plates/pla/plate_enclosures.3mf
166.0 x 120.0 x 30.0 mm
mcu_box_base_0
mcu_box_lid_1
hx711_box_base_2
hx711_box_base_3
hx711_box_base_4
hx711_box_base_5
hx711_box_lid_6
hx711_box_lid_7
hx711_box_lid_8
hx711_box_lid_9

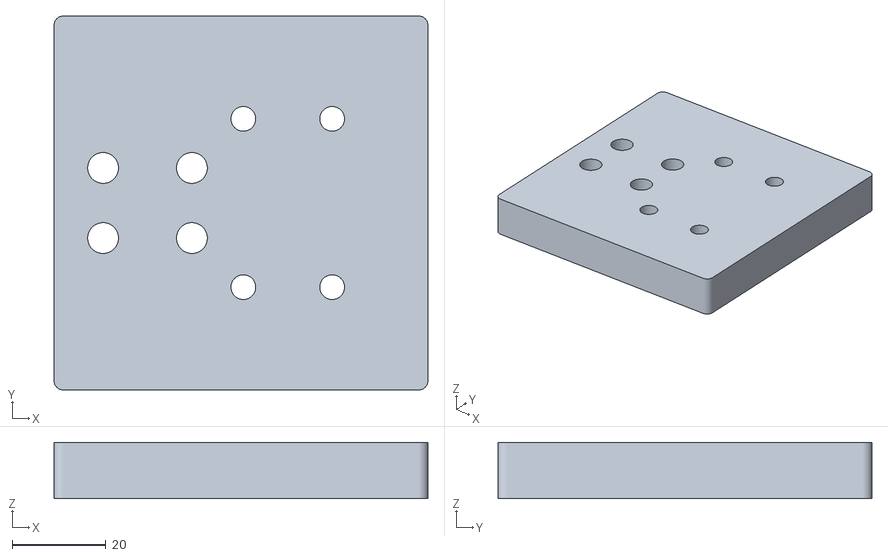
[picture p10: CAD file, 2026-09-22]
hardware/stl/rail_adapter.stl
80.0 x 80.0 x 12.0

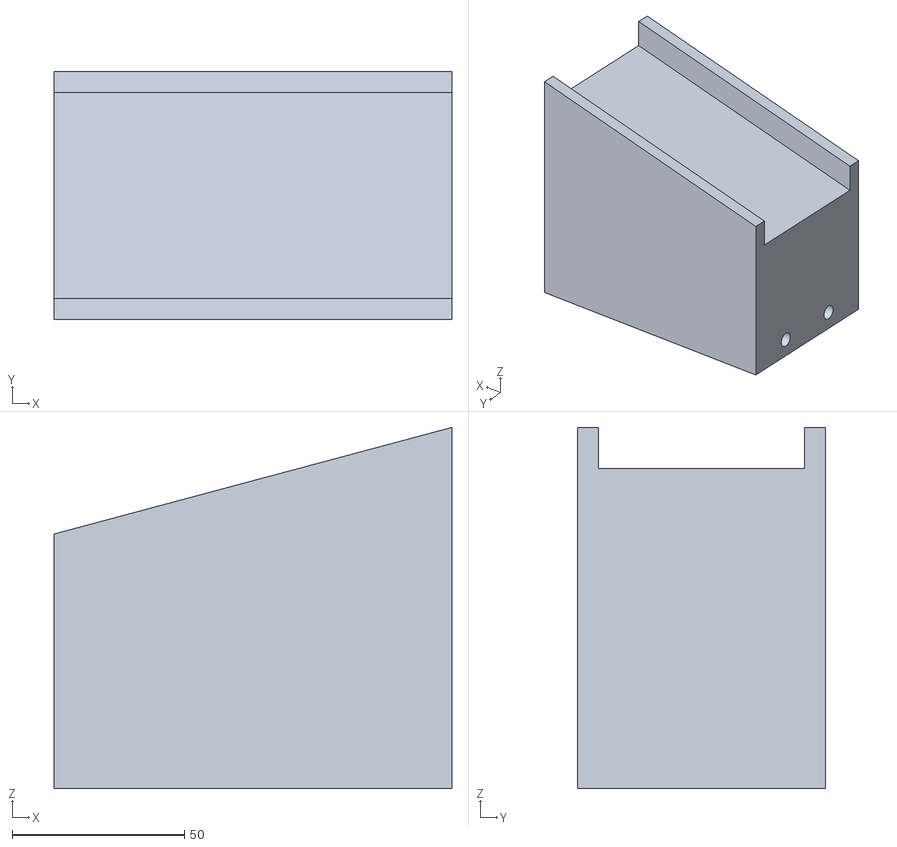
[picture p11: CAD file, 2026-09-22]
hardware/stl/rail_ramp_seg2.stl
115.7 x 72.0 x 105.0

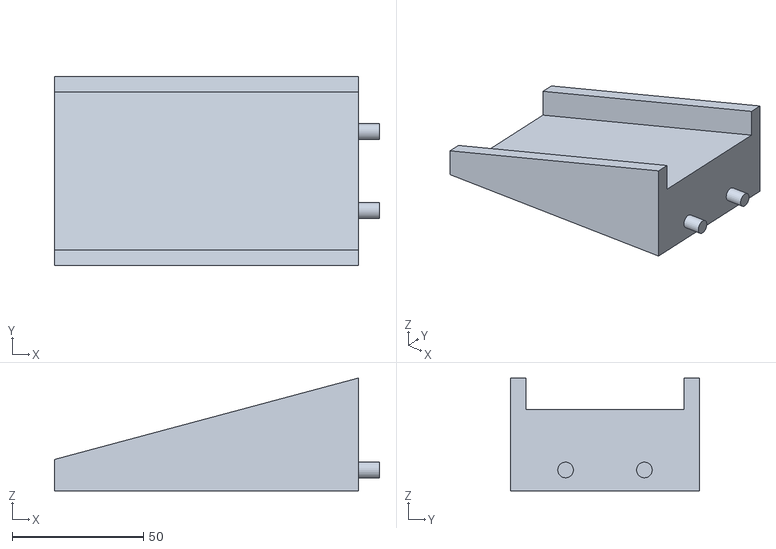
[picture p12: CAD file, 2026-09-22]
hardware/stl/rail_ramp_seg0.stl
123.7 x 72.0 x 43.0

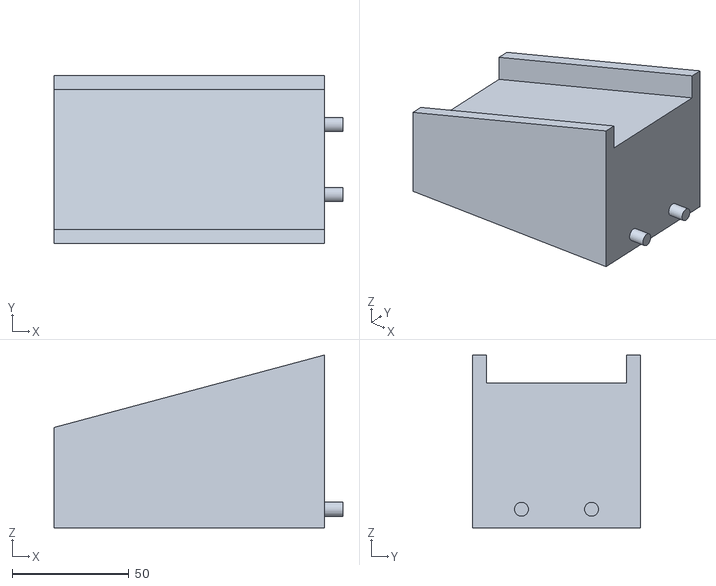
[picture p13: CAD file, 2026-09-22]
hardware/stl/rail_ramp_seg1.stl
123.7 x 72.0 x 74.0

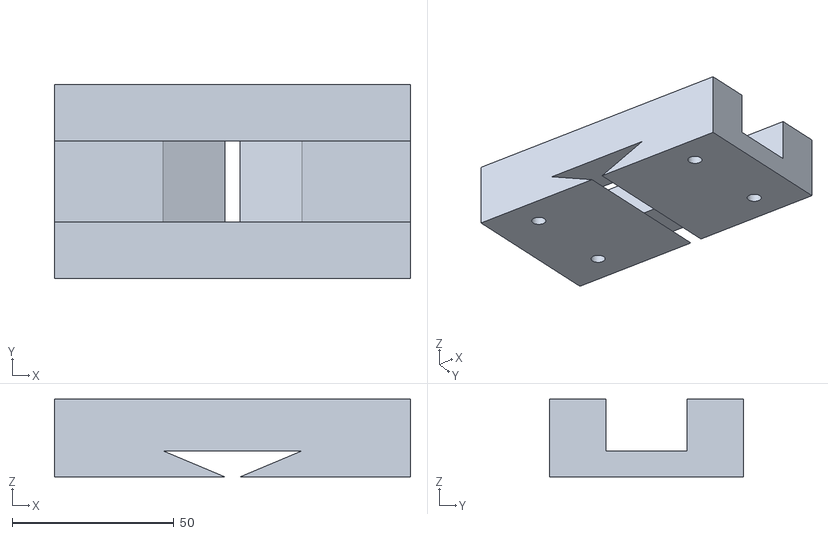
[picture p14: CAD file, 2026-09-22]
hardware/stl/wheel_cradle.stl
110.0 x 60.0 x 24.0

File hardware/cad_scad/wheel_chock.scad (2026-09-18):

// ===== 바퀴 고임목 (안착 후 삽입해 고정) =====
// 크래들에 바퀴가 들어온 뒤 앞뒤로 하나씩 끼워 이탈 방지.
include <rail_spec.scad>
$fn=32;
ch_w = wheel_thk + 2;
ch_l = 45; ch_h = 22;
difference(){
    hull(){
        translate([0,0,0]) cube([ch_l, ch_w, 1]);
        translate([ch_l-14,0,0]) cube([14, ch_w, ch_h]);
    }
    // 바퀴 곡률 릴리프
    translate([ch_l+wheel_d/2-6, -1, ch_h*0.55]) rotate([-90,0,0])
        cylinder(d=wheel_d, h=ch_w+2);
    // 손잡이 홀
    translate([12, ch_w/2, -1]) cylinder(d=8, h=ch_h+2);
}

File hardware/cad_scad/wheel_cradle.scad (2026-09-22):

// ===== 바퀴 크래들 (레일 위 캐스터 안착부) =====
// 얕은 V홈이라 앞바퀴가 굴러 지나갈 수 있고, 뒷바퀴는 여기 안착.
// 안착 후 wheel_chock(고임목)을 끼워 고정.
include <rail_spec.scad>
$fn=48;

cr_l = 110;             // 레일 길이방향
cr_w = RAIL_w;
cr_base = 8;            // 레일에 얹히는 바닥 두께
lip_h = 16;             // 바퀴 이탈 방지 측벽

slot_w  = wheel_thk + 3;              // 바퀴 두께 + 여유 (바퀴가 들어갈 홈 폭)
wall_w  = (cr_w - slot_w) / 2;        // 좌우 측벽 각각의 폭

// V홈: 바퀴 지름 기반으로 개구 폭 산출.
// 얕은 V(깊이 CRADLE_depth)에서 바퀴 원과의 접점이 만드는 현(chord) 폭.
// 바퀴 반지름 r, 홈 깊이 d 일 때 개구 반폭 = sqrt(r^2 - (r-d)^2).
V_r     = wheel_d / 2;
V_open  = 2 * sqrt(max(V_r*V_r - (V_r - CRADLE_depth)*(V_r - CRADLE_depth), 0.01));

// --- 실측 강제 (rail_spec 기본값=가정치이면 실물과 안 맞음) ---
// 주: V홈 개구폭은 슬롯폭보다 넓은 게 정상이다. 측벽 상단 립은 남고
//     그 아래를 바퀴 곡률에 맞춰 넓게 파내는 구조이기 때문. 다만 크래들
//     전체 폭(cr_w)을 넘으면 측벽이 통째로 사라지므로 그건 막는다.
assert(wheel_thk > 0, "wheel_thk 실측값을 rail_spec.scad 에 설정하세요");
assert(wheel_d   > 0, "wheel_d 실측값을 rail_spec.scad 에 설정하세요");
assert(V_open <= cr_w,
       "V홈 개구폭이 크래들 전체폭을 넘음 — CRADLE_depth 를 줄이거나 바퀴 지름 확인");

module cradle(){
    echo(str("크래들 ",cr_l,"x",cr_w," / 슬롯 ",slot_w," / 측벽 ",wall_w,
             " / V홈폭 ",V_open," 깊이 ",CRADLE_depth," (바퀴 d",wheel_d," t",wheel_thk,")"));
    difference(){
        union(){
            cube([cr_l, cr_w, cr_base]);
            // 좌우 측벽(리브) — y=0 쪽과 y=cr_w-wall_w 쪽, 각 폭 wall_w
            for(yoff = [0, cr_w - wall_w])
                translate([0, yoff, cr_base])
                    cube([cr_l, wall_w, lip_h]);
        }
        // 얕은 V 크래들 (개구 폭 = V_open, 깊이 = CRADLE_depth)
        translate([cr_l/2, cr_w/2, cr_base])
            rotate([90,0,0])
              translate([0,0,-cr_w])
                linear_extrude(cr_w*2)
                  polygon([[-V_open/2, 0.01],
                           [ V_open/2, 0.01],
                           [ 0, -CRADLE_depth]]);
        // 레일 체결 M5 x4
        for(dx=[18, cr_l-18]) for(dy=[12, cr_w-12])
            translate([dx,dy,-1]) cylinder(d=5.3,h=cr_base+2);
    }
}
cradle();

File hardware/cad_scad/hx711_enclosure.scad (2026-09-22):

// ===== HX711 인클로저 (바퀴 유닛당 1개) =====
// PDF 부품목록 확정: 외형 34 x 24 x 16mm. 기판 SZH-SSBH-054 25 x 15mm.
// 로드셀 신호 in <-> ESP32(SCK 공유) out. 하중경로 아님 -> PLA 가능.
// 체결: 볼트 + 육각너트 트랩 관통.
//
// part="base" : 박스 본체(바닥 + 4벽 + 기판 지지 립)
// part="lid"  : 뚜껑
include <rail_spec.scad>
part = "base";
$fn = 32;

// --- 외형 (PDF 확정) ---
BOX_L = 34; BOX_W = 24; BOX_H = 16;
WALL  = 2;                   // 소형이라 2mm
FILLET = 1.5;

// --- HX711 기판 (확정 25x15) ---
PCB_L = 25; PCB_W = 15;
LEDGE_H = 3;                 // 기판 안착 립 높이
LEDGE_W = 1.5;               // 립 폭

// --- 뚜껑 체결 (소형 M2) ---
LID_BOLT_D = 2.4;            // M2 관통
LID_NUT_AF = 4.2;           // M2 육각너트 대변 + 여유
LID_NUT_H  = 1.8;

module rrect(l,w,h,r){ hull() for(x=[r,l-r]) for(y=[r,w-r]) translate([x,y,0]) cylinder(r=r,h=h); }

// 케이블 인출구: 짧은 변 양쪽
module cable_slots(){
    // 좌: 로드셀 신호 (Ex/Sig 4선)
    translate([-2, BOX_W/2-5, WALL+2]) cube([WALL+4, 10, 6]);
    // 우: ESP32 (VCC/GND/DT/SCK)
    translate([BOX_L-WALL-2, BOX_W/2-5, WALL+2]) cube([WALL+4, 10, 6]);
}

// 대각 두 모서리 체결(소형이라 2점이면 충분). 기둥(d=5,r=2.5)이 벽 안쪽면과
// 정확히 일치하지 않도록 WALL+2 에 배치 -> 벽 속으로 0.5 겹침(union 안전).
bp = WALL + 2;
bolt_pts = [[bp, bp], [BOX_L-bp, BOX_W-bp]];

module base(){
    echo(str("HX711 박스 base ",BOX_L,"x",BOX_W,"x",BOX_H," 벽",WALL,
             " / PCB ",PCB_L,"x",PCB_W));
    difference(){
        union(){
            // 바닥 + 4벽 (윗면 개방), 내부 캐비티는 단순 큐브
            difference(){
                rrect(BOX_L, BOX_W, BOX_H, FILLET);
                translate([WALL, WALL, WALL])
                    cube([BOX_L-2*WALL, BOX_W-2*WALL, BOX_H]);
            }
            // 기판 안착 립 (좌우 긴 변 안쪽). 벽과 0.5 겹치게 해 면 일치(non-manifold) 회피.
            for(sy=[WALL-0.5, BOX_W-WALL-LEDGE_W+0.5])
                translate([WALL-0.5, sy, WALL]) cube([BOX_L-2*WALL+1, LEDGE_W, LEDGE_H]);
            // 뚜껑 체결 기둥 (바닥부터, 벽과 겹침)
            for(p=bolt_pts)
                translate([p[0],p[1],0]) cylinder(d=5, h=BOX_H-2);
        }
        // 뚜껑 볼트 관통 (바닥~기둥 상단 관통)
        for(p=bolt_pts)
            translate([p[0],p[1],-1]) cylinder(d=LID_BOLT_D, h=BOX_H+2);
        cable_slots();
    }
}

module lid(){
    echo(str("HX711 박스 lid ",BOX_L,"x",BOX_W));
    difference(){
        rrect(BOX_L, BOX_W, WALL, FILLET);
        for(p=bolt_pts){
            translate([p[0],p[1],-1]) cylinder(d=LID_BOLT_D, h=WALL+2);
            translate([p[0],p[1],WALL-LID_NUT_H])
                cylinder(d=LID_NUT_AF/cos(30), h=LID_NUT_H+0.1, $fn=6);
        }
    }
}

// rail_system.scad 조립 뷰 호환 별칭 (박스 본체 형상)
module hx711_body(){ base(); }

if(part=="base") base(); else lid();

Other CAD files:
hardware/stl/wheel_chock.stl
hardware/stl/rail_pad.stl
hardware/stl/mcu_box_base.stl
hardware/stl/hx711_box_lid.stl
hardware/cad_scad/mcu_enclosure.scad
hardware/cad_scad/rail_loadcell_mount.scad
hardware/cad_scad/rail_ramp_segment.scad
hardware/cad_scad/rail_spec.scad
hardware/cad_scad/rail_system.scad
hardware/plates/petg/plate_adapter_cradle.stl
hardware/plates/petg/plate_pads.stl
hardware/plates/pla/plate_chock_enclosures.stl
hardware/plates/pla/plate_chock_ramp.stl
hardware/plates/pla/plate_enclosures.stl

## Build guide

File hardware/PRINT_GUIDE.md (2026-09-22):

# 3D 프린팅 가이드

## 출력해야 하는 파일 (7종 · 총 26개)

`02_CAD/출력용_stl/` 안의 STL만 출력합니다. `.scad`는 소스이므로 프린터에 넣지 않습니다.

| STL 파일 | 부품 | 치수 (mm) | 수량 | 근거 |
|---|---|---|---|---|
| `rail_pad.stl` | 바닥 패드 + 단상 + **하면 4점 지지 발** | 200×50×13.5 | **4** | 로드셀 4개 |
| `rail_bracket.stl` | 로드셀 자유단 ↔ 레일 연결 | 90×60×**8** | **4** | 로드셀 4개 |
| `wheel_cradle.stl` | 바퀴 안착 V 크래들 | 110×60×24 | **4** | 캐스터 4개 |
| `wheel_chock.stl` | 고임목 | 42×24×22 | **8** | 바퀴당 앞뒤 2개 |
| `rail_ramp_seg0.stl` | 램프 (바닥측) + 다웰 핀 | 118.7×72×42 | **2** | 레일 2개 |
| `rail_ramp_seg1.stl` | 램프 (중간) + 다웰 | 118.7×72×71 | **2** | 레일 2개 |
| `rail_ramp_seg2.stl` | 램프 (레일측) + 다웰 홈 | 110.7×72×101 | **2** | 레일 2개 |

> **다웰 결합:** 램프 세그먼트는 접합면에 핀(⌀6, 8mm 돌출)과 구멍(⌀6.35)이 있어 서로 끼워집니다. seg0끝→seg1시작→seg1끝→seg2시작 순으로 결합. 핀 때문에 seg0/seg1의 X 길이가 8mm 더 깁니다.

**출력하지 않는 것:** `.scad` 파일 전부, `README.md`

---

## 출력 전에 반드시 — 치수 검증

지금 STL은 **가정값으로 뽑혀 있습니다.**

```
wheel_d      = 60    // 바퀴 지름  ← 실측 필요
wheel_thk    = 22    // 바퀴 두께  ← 실측 필요
CRADLE_depth = 9     // V홈 깊이   ← 실물 테스트 필요
```

크래들 슬롯 폭은 `wheel_thk + 3`, 고임목 폭은 `wheel_thk + 2`로 바퀴 두께에 직접 묶여 있습니다. 실제 바퀴가 22mm가 아니면 **크래들과 고임목은 그대로 못 씁니다.** 캘리퍼스로 재고 `rail_spec.scad`를 고친 뒤 재생성하세요.

패드·브래킷·램프는 바퀴 치수와 무관하므로 지금 STL로 출력해도 됩니다.

---

## 재료 선택 — PLA를 쓰면 안 되는 부품이 있습니다

`rail_pad`와 `rail_bracket`은 **하중 경로에 직렬로 들어갑니다.**

```
바닥 → [rail_pad] → 로드셀 → [rail_bracket] → 레일 → 바퀴 → 침대
```

즉 침대 하중의 1/4(로드셀 정격 100kg 기준 최대 100kg)이 이 두 부품을 상시 통과합니다. 문제는 하중의 크기가 아니라 **지속 시간**입니다.

PLA는 상온에서도 **크리프(creep)** 가 일어납니다. 일정 하중을 며칠간 계속 받으면 소성 변형이 서서히 누적되는데, 이게 계측에 치명적인 이유는 파손 때문이 아닙니다. 부품이 천천히 눌리면 **로드셀 영점이 계속 밀립니다.** 낙상 감지는 COG의 미세한 이동을 보는 시스템인데, 센서 지지 구조가 스스로 변형하면 그 드리프트가 신호에 섞여 들어갑니다. 재영점을 아무리 돌려도 원인이 사라지지 않습니다.

> **이 프로젝트 결정:** 하중 경로 부품은 **PETG**로 출력합니다 (밤부랩 H2D). 세팅은 아래 "밤부랩 H2D + PETG 출력 세팅" 섹션 참고.

| 부품 | 권장 재료 | 이유 |
|---|---|---|
| `rail_pad`, `rail_bracket` | **PETG** (택: ABS/ASA), 인필 60%+, 벽 5겹 | 지속 하중 크리프 방지. 여유가 되면 알루미늄 절삭품이 가장 확실 |
| `wheel_cradle` | PETG 권장, 인필 40% | 바퀴 하중 + 굴림 마찰 |
| `wheel_chock` | PLA 가능, 인필 30% | 측면 걸림 역할, 지속 압축 없음 |
| `rail_ramp_seg*` | PLA 가능, 인필 10~15% | 진입 시 순간 하중만. **하중 경로와 분리된 부품** |

램프 인필을 낮게 잡아도 되는 근거는 설계 원칙에 있습니다 — 램프가 로드셀 지지 구조에 닿으면 하중이 두 경로로 갈라져 측정값이 왜곡됩니다. 그래서 램프는 애초에 **독립 부품**으로 설계됐고, 침대가 올라탄 뒤에는 하중을 전혀 받지 않습니다.

---

## 출력량 — 미리 알고 시작하세요

솔리드 부피 합계 약 **3,000 cm³**입니다. 인필과 벽을 감안한 실사용량은 대략 **1.2~1.5 kg** (PLA 기준 1.5 스풀).

그중 **램프 3종이 2,127 cm³로 전체의 71%** 를 차지합니다. 램프만 프린팅으로 해결하려면 며칠이 걸립니다.

현실적인 대안:
- 램프 인필 10% + 상하면 3겹으로 낮추기 (강도는 충분합니다)
- 램프를 **합판이나 각목으로 제작** — 15° 경사면만 만들면 되는 단순 형상이고, 정밀도가 전혀 필요 없는 부품입니다
- 시제품 단계라면 **레일 1개분만** 먼저 출력해 검증 (패드 2, 브래킷 2, 크래들 2, 고임목 4, 램프 1세트)

---

## 밤부랩 H2D + PETG 출력 세팅

로드셀 하중 경로(`rail_pad`, `rail_bracket`)는 **PETG로 출력**합니다. H2D 기준 세팅입니다.

### 왜 PETG인가 (재확인)

`rail_pad`와 `rail_bracket`은 침대 하중의 1/4(로드셀 CAS BCA-100L 정격 100kg)을 **상시** 통과시키는 하중 경로에 직렬로 들어갑니다. PLA는 상온에서도 지속 하중을 받으면 크리프(creep)로 서서히 눌리고, 그러면 로드셀 영점이 계속 밀려 낙상 감지 신호에 드리프트가 섞입니다. PETG는 크리프 저항이 PLA보다 크게 우수해 이 용도에 적합합니다. (여유가 되면 이 2종만 알루미늄 절삭품이 가장 확실합니다.)

### 필라멘트 준비

- **Bambu PETG-HF** 또는 동급 PETG 권장 (H2D 프로파일 안정적, 워핑 적음)
- PETG는 흡습에 민감 → 출력 전 건조 필수. AMS 건조 기능 사용 또는 65℃ 6~8h 사전 건조
- AMS에 물릴 경우 습도 표시 확인. 눅눅하면 표면 거칠고 층간 접착이 약해져 크리프 저항이 떨어집니다

### H2D 슬라이서 프로파일 (Bambu Studio)

하중 경로 부품(`rail_pad`, `rail_bracket`) 기준:

| 항목 | 값 | 근거 |
|---|---|---|
| 노즐 온도 | 250~260℃ | PETG 표준. 층간 접착 확보 위해 하한보다 살짝 높게 |
| 베드 온도 | 70~80℃ | PETG 밀착 |
| 벽(월) 수 | **5겹 (2mm)** | 하중 경로 강성 |
| 상/하면 | **5겹** | 압축면 강성 |
| 인필 | **60% 이상**, Grid 또는 Gyroid | 지속 하중 크리프 방지 |
| 층 높이 | 0.16~0.20mm | 얇을수록 층간 접착 면적↑ (크리프에 유리) |
| 출력 속도 | 표준의 70~80%로 하향 | PETG는 과속 시 층간 접착 저하 |
| 냉각 팬 | 30~50% (과냉각 금지) | PETG는 팬 세면 층 분리 → 하중 부품에 치명적 |
| 리트랙션 | PETG 프로파일 기본값(스트링 주의) | - |
| 브림 | 필요 시 사용 | 얇고 넓은 브래킷 밀착 |

> **주의:** PLA 감각으로 팬 100% + 고속으로 뽑으면 층간 접착이 약해져 크리프 저항이 무너집니다. PETG 하중 부품은 "느리게, 덜 식히고, 두껍게"가 원칙입니다.

### H2D 활용 노트

- H2D 베드는 **350×320mm**로 넓습니다. 배치 출력용 **plate STL을 미리 만들어 뒀습니다** → `hardware/plates/` 참고. 26개 부품이 3판으로 묶여 있어 출력 준비 시간을 줄일 수 있습니다:
  - `plate1_pads.stl` — rail_pad ×4
  - `plate2_bracket_cradle.stl` — bracket ×4 + cradle ×4
  - `plate3_chock_ramp.stl` — chock ×8 + ramp ×6 (부피 커서 시간 오래 걸림, 램프 인필 낮추기 권장)
  - Bambu Studio에서 열면 개별 오브젝트로 인식되어 재배치·개별 인필 설정 가능
- H2D의 듀얼 노즐/멀티컬러는 이 부품에선 불필요(단색·단일재질). 한 노즐로 배치하면 됩니다
- ASA도 크리프 저항 대안이나, H2D는 챔버 히터가 없어 워핑 관리가 까다롭습니다. **PETG가 H2D에서 가장 무난한 선택**입니다

---

## 출력 방향

| 부품 | 베드에 놓는 면 | 이유 |
|---|---|---|
| `rail_pad` | **지지 발이 아래로** 향하게(단상은 위) | 발 4점이 베드에 닿음. 적층 방향 ⊥ 압축 하중 → 층간 분리 최소. 발 밑에 브림 권장 |
| `rail_bracket` | 넓은 평면 | 위와 동일. 서포트 불필요 |
| `wheel_cradle` | 바닥면 | V홈이 위를 향함. 서포트 불필요 |
| `wheel_chock` | 넓은 바닥면 | 경사면이 위로. 서포트 불필요 |
| `rail_ramp_seg*` | 경사 반대쪽 평면 | 측벽이 오버행이 되지 않도록. **다웰 핀은 옆면으로 돌출** → 서포트 없이 출력되나 핀 처짐 시 브림/각도 조정 |

전 부품 서포트 없이 출력 가능한 형상입니다. 패드 지지 발(2.5mm)은 얇으니 첫 층 밀착에 유의하세요.

---

## 출력 후 체크리스트

- [ ] **패드 4점 지지 발이 평평한지** — 4개가 같은 평면에 닿아야 흔들림 없이 영점 안정. 첫 층 들뜸 있으면 사포로 정리
- [ ] 패드 하면 카운터보어(⌀11.5)에 M6 볼트 머리가 들어가는지 — 발 때문에 하면이 떠 있어 볼트 머리는 바닥에 안 닿음(정상)
- [ ] 브래킷 중앙 4홀(19×15 피치)이 로드셀 자유단 탭과 맞는지 (두께 8mm 맞는 M6 볼트 길이 확인)
- [ ] **로드셀 자유단이 확실히 떠 있는지** — 고정단만 단상에 물리고 나머지는 공중에 떠야 정상 측정됩니다. 여기가 닿으면 측정값이 통째로 죽습니다
- [ ] **램프 다웰 결합** — seg0↔seg1↔seg2 핀이 구멍에 들어가 세그먼트가 밀리지 않는지 (뻑뻑하면 구멍 리머로 살짝 확장)
- [ ] 크래들에 실제 바퀴를 굴려 넣어 앞바퀴 통과 + 뒷바퀴 안착이 동시에 되는지 (**바퀴 실측 후 `wheel_thk`/`wheel_d` 반영 필수** — 미반영 시 크래들 렌더가 assert로 막힘)
- [ ] T너트가 알루미늄 프로파일 슬롯에 맞는지 (30×60 프로파일 슬롯 규격 확인)

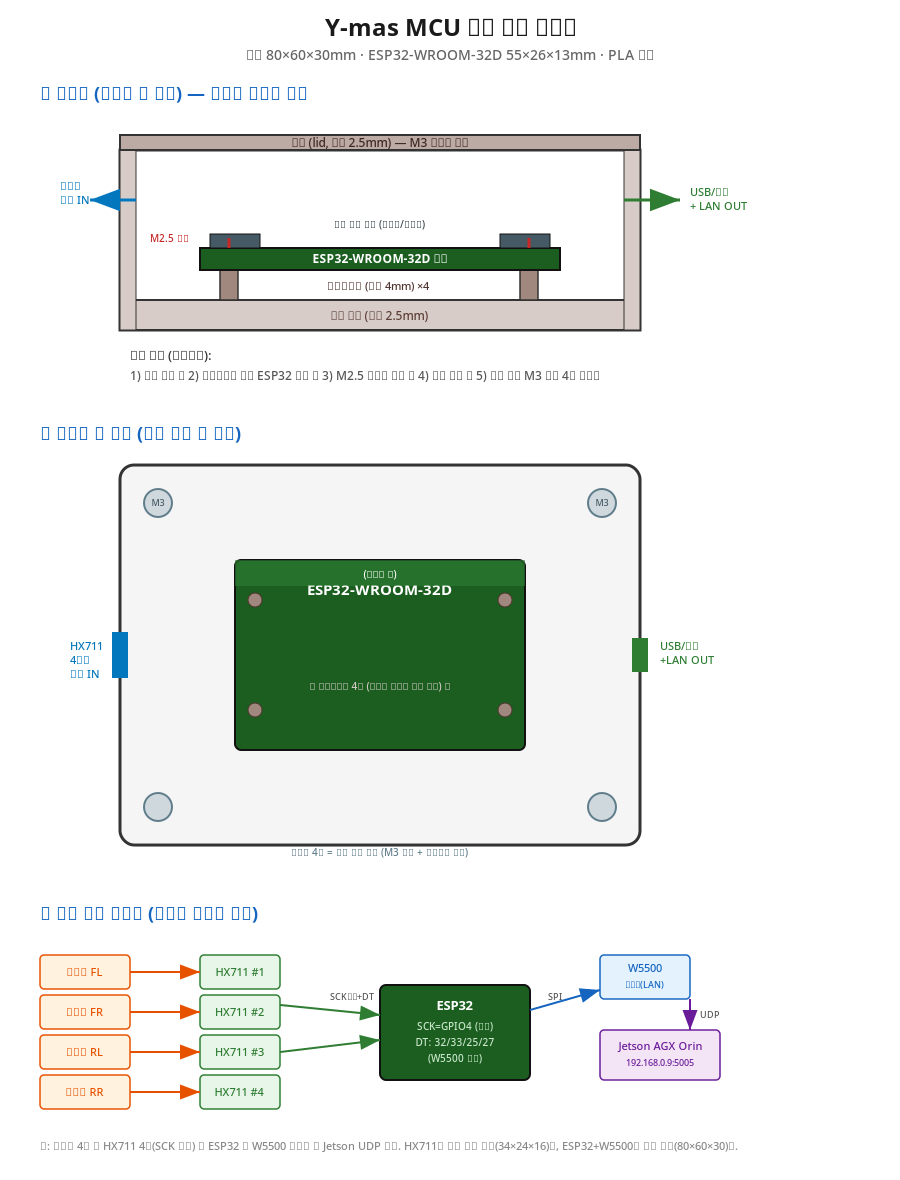
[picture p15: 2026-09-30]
hardware/docs/mcu_assembly.png

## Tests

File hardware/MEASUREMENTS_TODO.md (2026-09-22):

# 실측 체크리스트 — 기구 최종 출력 전 확정 필요

현재 CAD는 아래 값들이 **가정값(플레이스홀더)**으로 들어가 있습니다.
실측 후 `cad_scad/rail_spec.scad`(또는 표시된 파일)를 고치고 STL을 재생성하세요.
특히 캐스터 피치·레일 간격은 **COG 계산식에 직접** 들어가 낙상 감지 성능을 좌우합니다.

> 참고: 로드셀 두께를 22mm로 가정했다가 실제 40mm로 밝혀져 기구를 전면
> 재설계한 전례가 있음(참조 PDF). 가정값은 기구 전체를 무효화할 수 있으니
> **제작 착수 전 이 표를 먼저 소화할 것.**

---

## A. 바퀴 (캐스터) — 크래들·고임목에 직결

| # | 값 | 현재 가정값 | 어디를 재나 | 반영 위치 |
|---|---|---|---|---|
| A1 | 바퀴 지름 `wheel_d` | **60 mm** | 바퀴 바깥지름(가장 큰 원). 캘리퍼스 또는 자 | `rail_spec.scad` `wheel_d` |
| A2 | 바퀴 두께 `wheel_thk` | **22 mm** | 바퀴 폭(회전축 방향 두께). 캘리퍼스 | `rail_spec.scad` `wheel_thk` |
| A3 | V홈 깊이 `CRADLE_depth` | **9 mm** | 실물 테스트값 — 앞바퀴는 굴러 넘고 뒷바퀴는 안착되는 깊이 | `rail_spec.scad` `CRADLE_depth` |

- **주의:** 크래들 슬롯 폭 = `wheel_thk + 3`, 고임목 폭 = `wheel_thk + 2` 로 바퀴
  두께에 묶여 있음. A2가 틀리면 크래들·고임목 그대로 못 씀.
- A1/A2 미설정 시 `wheel_cradle.scad` 가 **assert 로 렌더를 막음**(가정치 방지).

---

## B. 침대 치수 — COG 계산에 직결 (가장 중요)

| # | 값 | 현재 가정값 | 어디를 재나 | 반영 위치 |
|---|---|---|---|---|
| B1 | 캐스터 피치 `CASTER_PITCH` | **1700 mm** | 침대 앞 캐스터 축 ↔ 뒤 캐스터 축 중심거리(길이방향) | `rail_spec.scad` + 펌웨어 `CASTER_PITCH` |
| B2 | 레일 간격 `RAIL_GAP` | **560 mm** | 좌 캐스터 ↔ 우 캐스터 중심거리(폭방향) | `rail_system.scad` `rail_gap` + 펌웨어 `RAIL_GAP` |

- `COG_X = CASTER_PITCH × (RL+RR)/total`, `COG_Y = RAIL_GAP × (FR+RR)/total`
- **CAD 뿐 아니라 펌웨어(`firmware/ymas_tier1_firmware.ino`)의 같은 값도 반드시 일치**시킬 것.
  펌웨어는 `dim <pitch> <gap>` 시리얼 명령으로도 설정 가능 → `save` 로 NVS 저장.
- B1 이 바뀌면 `RAIL_len = CASTER_PITCH + 400` 도 자동 변함(프로파일 절단 길이).

---

## C. 어댑터 플레이트 (로드셀 자유단 ↔ 레일 연결) — ⚠️ 설계 대기

참조 PDF 부품목록에 **어댑터 플레이트 80×80×12mm ×4** 가 있으나 현재 CAD에는
없음. 역할은 로드셀 40mm 대응 + **자유단 체결 홀이 바퀴 슬롯을 관통하지 않도록
레일 체결점을 수평 이격**시키는 것. (현 `rail_bracket` 을 이 규격으로 개정 예정.)

설계를 확정하려면 아래 실측이 필요:

| # | 값 | 어디를 재나 | 왜 필요 |
|---|---|---|---|
| C1 | 레일 체결점 오프셋 방향 | 조립 시 바퀴 슬롯(크래들)이 레일 위 어느 쪽에 오는지 | 어댑터가 자유단 홀에서 슬롯 **반대쪽**으로 뻗어야 함 |
| C2 | 레일 체결점 오프셋 거리 | 자유단 홀 중심 ↔ 슬롯 가장자리까지 여유 거리 | 볼트 자리와 바퀴 통로가 안 겹치는 최소 이격 |
| C3 | 레일 T너트/슬롯 규격 | 30×60 알루미늄 프로파일의 슬롯 폭·T너트 M5 규격 | 어댑터↔레일 체결 홀(현재 ⌀5.3 가정) |
| C4 | 어댑터 체결 볼트 길이 | 로드셀 자유단 탭(4-M6×1.0 DP15) + 어댑터 12mm | M6 볼트 길이 산출 |

- **불변 원칙:** 어댑터는 **자유단 2홀에만** 물리고, 로드셀 몸통·고정단 쪽과는
  떠 있어야 함. 닿으면 외팔보가 단락되어 측정이 죽음.
- 어댑터 12mm 도입 시 스택 높이 87→99mm 로 변함 → `DECK_Z`/`RAMP_len` 재계산 필요.

---

## D. 전자부 인클로저 — 부품목록엔 있으나 CAD 미복구

| # | 부품 | 확정 치수 | 현재 상태 | 필요 실측 |
|---|---|---|---|---|
| D1 | HX711 인클로저 | 34×24×16 mm (기판 25×15 확정) | `hx711_enclosure.scad` 미복구 | 케이블 인출구 위치 |
| D2 | 중앙 MCU 박스 | 80×60×30 mm | `mcu_enclosure.scad` 미복구 | ESP32 실물 외형(가정 55×28mm) + 커넥터 위치 |

- 이 둘은 하중 경로가 아니라 **전자부 보호용** → 급하지 않음. 실측 후 신규 설계.

---

## E. 공통 확인 (실측은 아니지만 제작 전 체크)

- [ ] 로드셀 자유단이 확실히 떠 있는지(고정단만 물림) — 조립 후 육안+틈새 게이지
- [ ] M6 볼트+육각너트 수량 산출(로드셀 4개 × 4-M6 + 인클로저 체결분)
- [ ] 알루미늄 프로파일 2100mm × 2 절단 발주 (B1 확정 후 `RAIL_len` 재확인)
- [ ] HX711 4개 RATE 핀 개조(트레이스 컷 + 15번→VCC 점퍼) → 80Hz 동작 확인
- [ ] 4채널 로드셀 캘리브레이션(영점 tare + 기준 분동 calall)

---

## 실측값 기입란 (여기 채워서 알려주세요 — CAD/펌웨어에 반영해 드립니다)

```
A1 바퀴 지름          = ____ mm
A2 바퀴 두께          = ____ mm
A3 V홈 깊이(테스트값)  = ____ mm   (모르면 9 유지하고 실물 테스트)
B1 캐스터 피치        = ____ mm
B2 레일 간격          = ____ mm
C1 슬롯 방향          = (바퀴가 레일 위 앞/뒤/좌/우 어느 쪽에서 진입?)
C2 오프셋 여유 거리    = ____ mm   (자유단 홀 ↔ 슬롯 가장자리)
C3 프로파일 슬롯/ T너트 = (예: 30x60 표준, M5 T너트)
D2 ESP32 실측 외형     = ____ x ____ mm
```

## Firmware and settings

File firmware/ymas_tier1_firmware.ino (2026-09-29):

/* =============================================================
 * Y-mas Tier 1 : 레일 플랫폼 하중 감지 펌웨어  (저지연판 v2)
 * Target : keyestudio ESP32-WROOM-32D (KS0413)
 * Sensor : CAS BCA-100L x4  ->  HX711 x4
 *
 * ============ v1 대비 지연 개선 ============
 *  (1) HX711 80Hz 모드      100ms -> 12.5ms 샘플 간격
 *  (2) 중앙값 필터          이동평균 대비 지연 절반, 스파이크 제거는 우수
 *  (3) 예측 감지            이탈도 변화율로 임계 도달 전 선행 알람
 *  (4) Fast Path            체중 급락 감지 시 확정 절차 생략
 *  (5) LAN UDP 전송         전송 지연 1ms 미만
 *  목표 반응 시간 : 0.15 ~ 0.30 초
 *
 * ============ 필수 하드웨어 개조 ============
 *  HX711 모듈의 RATE 핀(IC 15번)이 GND 에 연결되어 출고됩니다(10Hz).
 *  이 상태로는 샘플 간격이 100ms 라 저지연이 불가능합니다.
 *
 *   1. 모듈 뒷면에서 RATE(15번) -> GND 패턴을 커터로 절단
 *   2. 15번 핀을 VCC(DVDD) 로 점퍼
 *   3. 4개 모듈 모두 동일하게 작업
 *   -> 80Hz 모드. 노이즈는 약간 증가하나 중앙값 필터로 상쇄됩니다.
 *
 *  개조를 안 했다면 HX711_80HZ 를 0 으로 두십시오. 동작은 하되 느립니다.
 *
 * ============ 배선 ============
 *   HX711        ESP32
 *   VCC    <->   3V3 (또는 5V)
 *   GND    <->   GND
 *   SCK    <->   GPIO4   (4개 공통 -- 동시 샘플링)
 *   DT_FL  <->   GPIO16
 *   DT_FR  <->   GPIO17
 *   DT_RL  <->   GPIO18
 *   DT_RR  <->   GPIO19
 *
 *   로드셀: Ex+ 빨강 / Ex- 흰색 / Sig+ 파랑 / Sig- 초록 / Shield 검정
 *
 *   LAN (W5500 SPI 모듈 기준)
 *   MOSI GPIO23 / MISO GPIO19* / SCLK GPIO18* / CS GPIO5 / RST GPIO26
 *   * DT 핀과 충돌하므로 W5500 사용 시 DT 핀을 아래로 변경:
 *     DT_FL 32 / DT_FR 33 / DT_RL 25 / DT_RR 27
 * ============================================================= */

#include <Preferences.h>

// ---------- 빌드 옵션 ----------
#define HX711_80HZ    1     // RATE 핀 개조 완료 시 1
#define NET_MODE      1     // 0=시리얼만  1=W5500 LAN  2=WiFi

#if NET_MODE == 1
  #include <SPI.h>
  #include <Ethernet.h>
  #include <EthernetUdp.h>
  byte MAC_ADDR[] = {0xDE, 0xAD, 0xBE, 0xEF, 0xFE, 0x01};
  IPAddress ESP_IP   (192, 168, 0, 50);
  IPAddress JETSON_IP(192, 168, 0, 9);    // Jetson AGX Orin 실측 IP (재플래시 후 확정)
  const uint16_t JETSON_PORT = 5005;
  const int W5500_CS = 5;
  EthernetUDP udp;
#elif NET_MODE == 2
  #include <WiFi.h>
  #include <WiFiUdp.h>
  const char* WIFI_SSID = "YOUR_SSID";
  const char* WIFI_PASS = "YOUR_PASS";
  IPAddress JETSON_IP(192, 168, 0, 9);    // Jetson AGX Orin 실측 IP (재플래시 후 확정)
  const uint16_t JETSON_PORT = 5005;
  WiFiUDP udp;
#endif

// ---------- 핀 ----------
const int PIN_SCK = 4;
#if NET_MODE == 1
  const int PIN_DT[4] = {32, 33, 25, 27};   // W5500 과 충돌 회피
#else
  const int PIN_DT[4] = {16, 17, 18, 19};
#endif
enum { FL = 0, FR = 1, RL = 2, RR = 3 };
const char* CH_NAME[4] = {"FL", "FR", "RL", "RR"};

// ---------- 침대 실측값 ----------
float CASTER_PITCH = 1700.0f;   // mm
float RAIL_GAP     =  560.0f;   // mm

// ---------- 캘리브레이션 ----------
long  zeroOffset[4]  = {0, 0, 0, 0};
float scaleFactor[4] = {1.0f, 1.0f, 1.0f, 1.0f};

// ---------- 중앙값 필터 ----------
// 이동평균은 창 길이의 절반만큼 지연됩니다.
// 중앙값은 스파이크를 완전히 제거하면서 계단 응답 지연이 훨씬 작습니다.
#define MED_WIN 5
long  medBuf[4][MED_WIN];
int   medIdx = 0;
bool  medFilled = false;

void medPush(long raw[4]) {
  for (int i = 0; i < 4; i++) medBuf[i][medIdx] = raw[i];
  medIdx = (medIdx + 1) % MED_WIN;
  if (medIdx == 0) medFilled = true;
}

long median5(long a[MED_WIN], int n) {
  long t[MED_WIN];
  for (int i = 0; i < n; i++) t[i] = a[i];
  for (int i = 1; i < n; i++) {          // 삽입 정렬 (n=5, 매우 빠름)
    long k = t[i]; int j = i - 1;
    while (j >= 0 && t[j] > k) { t[j+1] = t[j]; j--; }
    t[j+1] = k;
  }
  return t[n / 2];
}

void medGet(float out[4]) {
  int n = medFilled ? MED_WIN : medIdx;
  if (n == 0) { for (int i=0;i<4;i++) out[i]=0; return; }
  for (int i = 0; i < 4; i++) out[i] = (float)median5(medBuf[i], n);
}

// ---------- 기준선 ----------
bool  baselineSet = false;
float baseW = 0.0f, baseCogX = 0.0f, baseCogY = 0.0f;

// ---------- 상태 ----------
enum State { S_EMPTY, S_NORMAL, S_CAUTION, S_DANGER, S_ALERT };
State curState = S_EMPTY;
const char* STATE_NAME[5] = {"EMPTY","NORMAL","CAUTION","DANGER","ALERT"};
const char* alertReason = "";

// ---------- 임계값 ----------
float TH_OCCUPIED  = 15.0f;    // kg
float TH_EDGE_CAUT = 0.40f;
float TH_EDGE_DANG = 0.62f;
float TH_COG_VEL   = 250.0f;   // mm/s
float TH_WLOSS     = 0.25f;    // 누적 체중 감소 비율

// 저지연 신규 임계값
float TH_WRATE     = -45.0f;   // kg/s, 체중 급락 속도 (Fast Path)
float TH_EDGE_RATE =  1.2f;    // /s, 이탈도 증가 속도
float TH_TTE       = 0.25f;    // s, 임계 도달 예상 시간
float TH_EDGE_PRED = 0.42f;    // 예측 감지를 켜는 최소 이탈도
int   CONFIRM_N    = 2;

int  dangerHits = 0;
unsigned long lastAlertMs = 0;
const unsigned long ALERT_COOLDOWN_MS = 8000;

// ---------- 자동 영점 보정 (auto-tare) ----------
// 목적: PETG 지지 구조의 크리프(creep)로 zeroOffset 이 서서히 밀리는 것을 보정.
// 원리: 침대가 확실히 비어 있고(raw 가 zeroOffset 근처) 값이 안정적일 때만,
//       zeroOffset 을 아주 천천히(EMA) raw 쪽으로 끌어당긴다.
//       크리프처럼 느린 드리프트만 추종하고, 사람이 올라오는 급변은 무시.
bool  autoTareEnabled = true;
float AT_ALPHA        = 0.02f;    // EMA 계수 (작을수록 느리게 추종)
float AT_STABLE_KG    = 0.30f;    // 이 kg 이하 변동이어야 "안정"으로 간주
uint32_t AT_HOLD_MS   = 3000;     // 빈 상태가 이만큼 지속돼야 보정 시작
long  AT_MAX_STEP     = 500;      // 1회 보정 최대 이동량(raw count) — 폭주 방지
uint32_t atEmptySince = 0;        // S_EMPTY 진입 시각 (0=미진입)
uint32_t lastAutoTareMs = 0;
long  lastAutoTareDelta[4] = {0,0,0,0};   // 진단용: 마지막 보정 이동량

// ---------- 미분 계산 (지연 최소화를 위해 짧은 창) ----------
#define DERIV_WIN 4
float  hEdge[DERIV_WIN], hW[DERIV_WIN];
uint32_t hT[DERIV_WIN];
int   hIdx = 0; bool hFilled = false;

void derivPush(float edge, float w, uint32_t ms) {
  hEdge[hIdx] = edge; hW[hIdx] = w; hT[hIdx] = ms;
  hIdx = (hIdx + 1) % DERIV_WIN;
  if (hIdx == 0) hFilled = true;
}

// 가장 오래된 값과 최신 값의 차분 (선형 근사)
bool derivGet(float* dEdge, float* dW) {
  int n = hFilled ? DERIV_WIN : hIdx;
  if (n < 2) return false;
  int newest = (hIdx - 1 + DERIV_WIN) % DERIV_WIN;
  int oldest = hFilled ? hIdx : 0;
  float dt = (hT[newest] - hT[oldest]) / 1000.0f;
  if (dt < 1e-4f) return false;
  *dEdge = (hEdge[newest] - hEdge[oldest]) / dt;
  *dW    = (hW[newest]    - hW[oldest])    / dt;
  return true;
}

float prevCogX = 0, prevCogY = 0;
uint32_t prevMs = 0; bool prevValid = false;

Preferences prefs;

// =============================================================
// HX711 4채널 동시 리딩
// =============================================================
bool hxAllReady() {
  for (int i = 0; i < 4; i++)
    if (digitalRead(PIN_DT[i]) == HIGH) return false;
  return true;
}

void hxReadAll(long out[4]) {
  uint32_t v[4] = {0,0,0,0};
  noInterrupts();
  for (int b = 0; b < 24; b++) {
    digitalWrite(PIN_SCK, HIGH);
    delayMicroseconds(1);
    for (int i = 0; i < 4; i++)
      v[i] = (v[i] << 1) | (uint32_t)digitalRead(PIN_DT[i]);
    digitalWrite(PIN_SCK, LOW);
    delayMicroseconds(1);
  }
  digitalWrite(PIN_SCK, HIGH); delayMicroseconds(1);   // 25th: gain 128
  digitalWrite(PIN_SCK, LOW);  delayMicroseconds(1);
  interrupts();
  for (int i = 0; i < 4; i++) {
    if (v[i] & 0x800000UL) v[i] |= 0xFF000000UL;
    out[i] = (long)(int32_t)v[i];
  }
}

// 논블로킹: 준비 안 됐으면 즉시 false 반환 (루프를 막지 않음)
bool hxPoll(long out[4]) {
  if (!hxAllReady()) return false;
  hxReadAll(out);
  return true;
}

bool hxReadBlocking(long out[4], uint32_t timeoutMs = 300) {
  uint32_t t0 = millis();
  while (!hxAllReady()) {
    if (millis() - t0 > timeoutMs) return false;
    delayMicroseconds(200);
  }
  hxReadAll(out);
  return true;
}

// =============================================================
void toKg(const float rawAvg[4], float kg[4]) {
  for (int i = 0; i < 4; i++) {
    float d = rawAvg[i] - (float)zeroOffset[i];
    kg[i] = (fabsf(scaleFactor[i]) < 1e-6f) ? 0.0f : d / scaleFactor[i];
  }
}

struct Measure {
  float kg[4];
  float total, cogX, cogY, edgeRatio, cogVel;
  float dEdge, dW;      // 변화율
  float tte;            // 임계 도달 예상 시간 (s), 음수면 접근 안 함
  bool  valid;
};

Measure computeMeasure(const float kg[4]) {
  Measure m;
  for (int i = 0; i < 4; i++) m.kg[i] = kg[i];
  m.total = kg[FL] + kg[FR] + kg[RL] + kg[RR];
  m.dEdge = m.dW = 0.0f;
  m.tte = -1.0f;

  if (m.total < 1.0f) {
    m.cogX = m.cogY = m.edgeRatio = m.cogVel = 0.0f;
    m.valid = false;
    return m;
  }

  m.cogX = CASTER_PITCH * (kg[RL] + kg[RR]) / m.total;
  m.cogY = RAIL_GAP     * (kg[FR] + kg[RR]) / m.total;
  m.edgeRatio = fabsf(m.cogY / RAIL_GAP - 0.5f) * 2.0f;

  uint32_t now = millis();
  if (prevValid && now > prevMs) {
    float dt = (now - prevMs) / 1000.0f;
    float dx = m.cogX - prevCogX, dy = m.cogY - prevCogY;
    m.cogVel = sqrtf(dx*dx + dy*dy) / dt;
  } else m.cogVel = 0.0f;
  prevCogX = m.cogX; prevCogY = m.cogY; prevMs = now; prevValid = true;

  derivPush(m.edgeRatio, m.total, now);
  derivGet(&m.dEdge, &m.dW);

  // 임계 도달 예상 시간: 현재 증가 속도가 유지된다고 가정한 선형 외삽
  if (m.dEdge > 0.05f && m.edgeRatio < TH_EDGE_DANG)
    m.tte = (TH_EDGE_DANG - m.edgeRatio) / m.dEdge;

  m.valid = true;
  return m;
}

// =============================================================
// 상태 판정 -- 3경로 구조
//
//  Fast Path  : 체중 급락. 이미 낙하 중이므로 확정 절차 생략
//  Predictive : 이탈도가 임계 도달 예정. 도달 전에 선행 알람
//  Standard   : 기존 임계값 기반. 느리지만 확실
// =============================================================
State judge(const Measure& m) {
  alertReason = "";

  if (m.total < TH_OCCUPIED) { dangerHits = 0; return S_EMPTY; }
  if (!baselineSet) return S_NORMAL;

  float wLoss = (baseW > 1.0f) ? (baseW - m.total) / baseW : 0.0f;

  // ---- Fast Path : 체중 급락 ----
  // 정상 기상은 2~3초에 걸쳐 감소, 낙상은 0.3~0.5초에 급락.
  // dW/dt 가 -45kg/s 아래면 물리적으로 낙하 중.
  if (m.dW <= TH_WRATE && m.edgeRatio >= 0.30f) {
    alertReason = "FASTPATH_WEIGHT_DROP";
    return S_ALERT;                      // 확정 절차 생략
  }

  // ---- Predictive : 임계 도달 예측 ----
  if (m.edgeRatio >= TH_EDGE_PRED &&
      m.dEdge >= TH_EDGE_RATE &&
      m.tte > 0.0f && m.tte <= TH_TTE) {
    dangerHits++;
    if (dangerHits >= CONFIRM_N) {
      alertReason = "PREDICTIVE_EDGE_RATE";
      return S_ALERT;
    }
    return S_DANGER;
  }

  // ---- Standard ----
  bool edgeCaution = (m.edgeRatio >= TH_EDGE_CAUT);
  bool edgeDanger  = (m.edgeRatio >= TH_EDGE_DANG);
  bool fastMove    = (m.cogVel   >= TH_COG_VEL);
  bool weightDrop  = (wLoss      >= TH_WLOSS);

  if (edgeDanger && (fastMove || weightDrop)) {
    dangerHits++;
    if (dangerHits >= CONFIRM_N) {
      alertReason = "STANDARD_EDGE";
      return S_ALERT;
    }
    return S_DANGER;
  }
  if (edgeDanger || (edgeCaution && fastMove)) {
    dangerHits = max(0, dangerHits - 1);
    return S_DANGER;
  }
  if (edgeCaution) { dangerHits = 0; return S_CAUTION; }

  dangerHits = 0;
  return S_NORMAL;
}

// =============================================================
// 자동 영점 보정 (auto-tare)
//   st       : 이번 프레임 상태 (S_EMPTY 여야 후보)
//   avg[4]   : 중앙값 필터를 거친 raw 평균 (zeroOffset 차감 전)
//   m        : 현재 측정 (안정성 판단에 total 사용)
// 조건을 모두 만족할 때만 zeroOffset 을 EMA 로 소폭 이동한다.
// =============================================================
void autoTare(State st, const float avg[4], const Measure& m) {
  if (!autoTareEnabled) { atEmptySince = 0; return; }

  // 빈 상태가 아니면 타이머 리셋 후 종료 (사람이 있으면 절대 건드리지 않음)
  if (st != S_EMPTY) { atEmptySince = 0; return; }

  uint32_t now = millis();
  if (atEmptySince == 0) { atEmptySince = now; return; }

  // 빈 상태가 충분히 지속됐는지
  if (now - atEmptySince < AT_HOLD_MS) return;

  // 값이 안정적인지: 현재 total(빈 상태라 0 근처여야) 의 절대값이 작아야 함
  if (fabsf(m.total) > AT_STABLE_KG) return;

  // 초당 1회 정도로만 (과보정 방지)
  if (now - lastAutoTareMs < 1000) return;
  lastAutoTareMs = now;

  // 각 채널 zeroOffset 을 raw 쪽으로 EMA. 단, 1회 이동량은 AT_MAX_STEP 로 제한.
  for (int i = 0; i < 4; i++) {
    long target = (long)avg[i];
    long delta  = (long)((target - zeroOffset[i]) * AT_ALPHA);
    if (delta >  AT_MAX_STEP) delta =  AT_MAX_STEP;
    if (delta < -AT_MAX_STEP) delta = -AT_MAX_STEP;
    zeroOffset[i] += delta;
    lastAutoTareDelta[i] = delta;
  }
}

// =============================================================
// NVS
// =============================================================
void saveCal() {
  prefs.begin("ymas", false);
  for (int i = 0; i < 4; i++) {
    char k1[8], k2[8];
    snprintf(k1, sizeof(k1), "z%d", i);
    snprintf(k2, sizeof(k2), "s%d", i);
    prefs.putLong(k1, zeroOffset[i]);
    prefs.putFloat(k2, scaleFactor[i]);
  }
  prefs.putFloat("pitch", CASTER_PITCH);
  prefs.putFloat("gap",   RAIL_GAP);
  prefs.end();
  Serial.println("[OK] 캘리브레이션 저장");
}

void loadCal() {
  prefs.begin("ymas", true);
  for (int i = 0; i < 4; i++) {
    char k1[8], k2[8];
    snprintf(k1, sizeof(k1), "z%d", i);
    snprintf(k2, sizeof(k2), "s%d", i);
    zeroOffset[i]  = prefs.getLong (k1, 0);
    scaleFactor[i] = prefs.getFloat(k2, 1.0f);
  }
  CASTER_PITCH = prefs.getFloat("pitch", CASTER_PITCH);
  RAIL_GAP     = prefs.getFloat("gap",   RAIL_GAP);
  prefs.end();
  Serial.println("[OK] 캘리브레이션 복원");
}

// =============================================================
// 명령
// =============================================================
void printHelp() {
  Serial.println();
  Serial.println("===== Y-mas Tier 1 명령어 =====");
  Serial.println("  tare              무부하 영점 조정");
  Serial.println("  cal <ch> <kg>     채널 개별 보정");
  Serial.println("  calall <kg>       중앙 배치 4채널 보정");
  Serial.println("  base              환자 기준선 저장");
  Serial.println("  clearbase         기준선 해제");
  Serial.println("  dim <pitch> <gap> 캐스터 간격 (mm)");
  Serial.println("  th                임계값 출력");
  Serial.println("  set <name> <val>  임계값 변경");
  Serial.println("     occ caut dang vel wloss wrate erate tte epred confirm");
  Serial.println("     atalpha atstable athold");
  Serial.println("  rate              샘플링 속도 측정");
  Serial.println("  autotare [on|off] 빈 상태 자동 영점(크리프 보정) 상태/전환");
  Serial.println("  save / load / raw / help");
  Serial.println("===============================");
  Serial.println();
}

void doTare() {
  Serial.println("영점 조정 중... 침대에서 손을 떼세요.");
  long acc[4] = {0,0,0,0}; int ok = 0;
  for (int k = 0; k < 40; k++) {
    long r[4];
    if (hxReadBlocking(r)) { for (int i=0;i<4;i++) acc[i]+=r[i]; ok++; }
  }
  if (!ok) { Serial.println("[ERR] HX711 응답 없음"); return; }
  for (int i = 0; i < 4; i++) zeroOffset[i] = acc[i]/ok;
  medFilled = false; medIdx = 0; hFilled = false; hIdx = 0;
  Serial.print("[OK] 영점  ");
  for (int i=0;i<4;i++){ Serial.print(CH_NAME[i]); Serial.print("=");
                         Serial.print(zeroOffset[i]); Serial.print(" "); }
  Serial.println();
}

void doCal(int ch, float kg) {
  if (ch < 0 || ch > 3 || kg <= 0) { Serial.println("[ERR] cal <0~3> <kg>"); return; }
  Serial.print(CH_NAME[ch]); Serial.print(" 에 ");
  Serial.print(kg); Serial.println("kg 올린 상태로 측정...");
  long acc = 0; int ok = 0;
  for (int k = 0; k < 40; k++) { long r[4];
    if (hxReadBlocking(r)) { acc += r[ch]; ok++; } }
  if (!ok) { Serial.println("[ERR] 읽기 실패"); return; }
  float d = (float)acc/ok - (float)zeroOffset[ch];
  if (fabsf(d) < 100.0f) { Serial.println("[ERR] 변화량 부족"); return; }
  scaleFactor[ch] = d / kg;
  Serial.print("[OK] scale="); Serial.println(scaleFactor[ch], 2);
}

void doCalAll(float kg) {
  if (kg <= 0) { Serial.println("[ERR] calall <kg>"); return; }
  Serial.print("중앙에 "); Serial.print(kg); Serial.println("kg 배치 후 측정...");
  long acc[4] = {0,0,0,0}; int ok = 0;
  for (int k = 0; k < 40; k++) { long r[4];
    if (hxReadBlocking(r)) { for(int i=0;i<4;i++) acc[i]+=r[i]; ok++; } }
  if (!ok) { Serial.println("[ERR] 읽기 실패"); return; }
  float d[4], sum = 0;
  for (int i=0;i<4;i++){ d[i]=(float)acc[i]/ok-(float)zeroOffset[i]; sum+=d[i]; }
  if (fabsf(sum) < 400.0f) { Serial.println("[ERR] 변화량 부족"); return; }
  for (int i = 0; i < 4; i++) {
    float share = kg * (d[i]/sum);
    if (fabsf(share) > 1e-3f) scaleFactor[i] = d[i]/share;
    Serial.print("  "); Serial.print(CH_NAME[i]);
    Serial.print(" "); Serial.print(share,2);
    Serial.print("kg  scale "); Serial.println(scaleFactor[i],2);
  }
  Serial.println("[OK] 완료");
}

void doBaseline(const Measure& m) {
  if (m.total < TH_OCCUPIED) { Serial.println("[ERR] 침대가 비어 있음"); return; }
  baseW = m.total; baseCogX = m.cogX; baseCogY = m.cogY;
  baselineSet = true;
  Serial.print("[OK] 기준선 W="); Serial.print(baseW,2);
  Serial.print("kg COG=("); Serial.print(baseCogX,1);
  Serial.print(","); Serial.print(baseCogY,1); Serial.println(")");
}

void printTh() {
  Serial.println("--- 임계값 ---");
  Serial.print("  occ     재실 kg        : "); Serial.println(TH_OCCUPIED,1);
  Serial.print("  caut    주의 이탈도    : "); Serial.println(TH_EDGE_CAUT,3);
  Serial.print("  dang    위험 이탈도    : "); Serial.println(TH_EDGE_DANG,3);
  Serial.print("  vel     COG 속도 mm/s  : "); Serial.println(TH_COG_VEL,1);
  Serial.print("  wloss   누적 감소 비율 : "); Serial.println(TH_WLOSS,3);
  Serial.print("  wrate   체중 급락 kg/s : "); Serial.println(TH_WRATE,1);
  Serial.print("  erate   이탈도 속도 /s : "); Serial.println(TH_EDGE_RATE,2);
  Serial.print("  tte     도달예측 s     : "); Serial.println(TH_TTE,3);
  Serial.print("  epred   예측 최소 이탈 : "); Serial.println(TH_EDGE_PRED,3);
  Serial.print("  confirm 확정 회수      : "); Serial.println(CONFIRM_N);
  Serial.print("  pitch/gap mm           : ");
  Serial.print(CASTER_PITCH,1); Serial.print(" / "); Serial.println(RAIL_GAP,1);
  Serial.print("  auto-tare              : ");
  Serial.print(autoTareEnabled ? "ON":"OFF");
  Serial.print("  alpha="); Serial.print(AT_ALPHA,3);
  Serial.print(" stable="); Serial.print(AT_STABLE_KG,2);
  Serial.print("kg hold="); Serial.print(AT_HOLD_MS); Serial.println("ms");
}

void doSet(String n, float v) {
  if      (n=="occ")     TH_OCCUPIED=v;
  else if (n=="caut")    TH_EDGE_CAUT=v;
  else if (n=="dang")    TH_EDGE_DANG=v;
  else if (n=="vel")     TH_COG_VEL=v;
  else if (n=="wloss")   TH_WLOSS=v;
  else if (n=="wrate")   TH_WRATE=v;
  else if (n=="erate")   TH_EDGE_RATE=v;
  else if (n=="tte")     TH_TTE=v;
  else if (n=="epred")   TH_EDGE_PRED=v;
  else if (n=="confirm") CONFIRM_N=(int)v;
  else if (n=="atalpha") AT_ALPHA=v;
  else if (n=="atstable")AT_STABLE_KG=v;
  else if (n=="athold")  AT_HOLD_MS=(uint32_t)v;
  else { Serial.println("[ERR] 알 수 없는 항목"); return; }
  Serial.print("[OK] "); Serial.print(n);
  Serial.print("="); Serial.println(v,3);
}

void doRateTest() {
  Serial.println("샘플링 속도 측정 (2초)...");
  uint32_t t0 = millis(); int cnt = 0; long r[4];
  while (millis() - t0 < 2000) if (hxPoll(r)) cnt++;
  float hz = cnt / 2.0f;
  Serial.print("[결과] "); Serial.print(hz,1); Serial.println(" Hz");
  if (hz < 20.0f) {
    Serial.println("  -> 10Hz 모드입니다. RATE 핀 개조 시 80Hz 가능.");
    Serial.println("     현재 상태로는 반응 지연 300ms 이상 예상.");
  } else if (hz > 60.0f) {
    Serial.println("  -> 80Hz 모드 정상. 저지연 동작 가능.");
  }
}
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
void loop() {
  static uint32_t lastEmit = 0;
  static Measure lastM;
  static bool everMeasured = false;

  long raw[4];
  if (hxPoll(raw)) {                 // 논블로킹 폴링
    medPush(raw);
    float avg[4], kg[4];
    medGet(avg);
    toKg(avg, kg);
    lastM = computeMeasure(kg);
    everMeasured = true;

    State st = judge(lastM);

    // 빈 상태에서 크리프 드리프트 자동 보정 (avg = zeroOffset 차감 전 raw)
    autoTare(st, avg, lastM);

    if (st == S_ALERT) {
      if (millis() - lastAlertMs < ALERT_COOLDOWN_MS) {
        st = S_DANGER;
      } else {
        lastAlertMs = millis();
        emitAlert(lastM);            // 주기 전송과 무관하게 즉시
        Serial.print(">>> INTERRUPT ("); Serial.print(alertReason);
        Serial.println(") Tier 2 기동 요청 <<<");
      }
    }
    curState = st;

    // 주기 전송 25ms (40Hz). 상태 변화 시에는 즉시.
    static State lastSent = S_EMPTY;
    if (millis() - lastEmit >= 25 || st != lastSent) {
      lastEmit = millis(); lastSent = st;
      emit(lastM, curState);
    }
  }

  if (Serial.available())
    handleCommand(Serial.readStringUntil('\n'),
                  everMeasured ? lastM : Measure{});
}

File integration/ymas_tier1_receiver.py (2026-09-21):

#!/usr/bin/env python3
"""
=============================================================
 Y-mas Tier 1 수신부 + Tier 2 연동  (Jetson 측)

 역할
   1) ESP32 로부터 하중/COG 데이터 수신 (Serial 또는 UDP)
   2) 상태 모니터링 및 로깅
   3) ALERT 수신 시 Tier 2 비전 AI 기동 (threading.Event)
   4) 하드웨어 없이 테스트하는 시뮬레이터 내장

 실행
   실물 :  python3 ymas_tier1_receiver.py --port /dev/ttyUSB0
   UDP  :  python3 ymas_tier1_receiver.py --udp 5005
   모의 :  python3 ymas_tier1_receiver.py --sim
=============================================================
"""
import argparse
import csv
import math
import os
import random
import socket
import threading
import time
from collections import deque
from datetime import datetime

# =============================================================
# 데이터 구조
# =============================================================
class Reading:
    """ESP32 가 보낸 한 프레임"""
    __slots__ = ('ms', 'state', 'total', 'cog_x', 'cog_y',
                 'edge', 'vel', 'd_edge', 'd_w', 'tte', 'reason',
                 'kg', 'recv_time')

    def __init__(self, ms, state, total, cog_x, cog_y, edge, vel,
                 d_edge, d_w, tte, reason, kg):
        self.ms        = ms
        self.state     = state
        self.total     = total
        self.cog_x     = cog_x
        self.cog_y     = cog_y
        self.edge      = edge
        self.vel       = vel
        self.d_edge    = d_edge      # 이탈도 변화율 /s
        self.d_w       = d_w         # 체중 변화율 kg/s
        self.tte       = tte         # 임계 도달 예상 s
        self.reason    = reason
        self.kg        = kg
        self.recv_time = time.time()

    def __repr__(self):
        return (f"[{self.state:7s}] W={self.total:6.2f}kg "
                f"COG=({self.cog_x:6.1f},{self.cog_y:5.1f}) "
                f"edge={self.edge:.3f} dE={self.d_edge:+6.2f}/s "
                f"dW={self.d_w:+7.1f}kg/s")


def parse_line(line):
    """
    YMAS,<ms>,<state>,<total>,<cogX>,<cogY>,<edge>,<vel>,
         <dEdge>,<dW>,<tte>,<reason>,<FL>,<FR>,<RL>,<RR>
    """
    line = line.strip()
    if not line.startswith('YMAS,'):
        return None
    p = line.split(',')
    if len(p) != 16:
        return None
    try:
        return Reading(
            ms     = int(p[1]),
            state  = p[2],
            total  = float(p[3]),
            cog_x  = float(p[4]),
            cog_y  = float(p[5]),
            edge   = float(p[6]),
            vel    = float(p[7]),
            d_edge = float(p[8]),
            d_w    = float(p[9]),
            tte    = float(p[10]),
            reason = p[11],
            kg     = [float(p[12]), float(p[13]),
                      float(p[14]), float(p[15])],
        )
    except ValueError:
        return None


def parse_alert(line):
    """YMAS_ALERT,<ms>,<total>,<cogX>,<cogY>,<edge>,<dW>,<reason>"""
    line = line.strip()
    if not line.startswith('YMAS_ALERT,'):
        return None
    p = line.split(',')
    if len(p) != 8:
        return None
    try:
        return dict(ms=int(p[1]), total=float(p[2]),
                    cog_x=float(p[3]), cog_y=float(p[4]),
                    edge=float(p[5]), d_w=float(p[6]), reason=p[7])
    except ValueError:
        return None


# =============================================================
# Tier 1 -> Tier 2 연동 컨트롤러
# =============================================================
class Tier1Controller:
    """
    ESP32 상태를 받아 Tier 2 기동 여부를 결정.

    ESP32 가 이미 1차 판정(ALERT)을 하지만, Jetson 쪽에서
    한 번 더 지속성을 확인해 순간 노이즈로 카메라가 켜지는 것을 방지.
    """
    def __init__(self, wake_event, log_path=None,
                 sustain_n=1, cooldown_s=8.0):
        self.wake_event = wake_event
        self.sustain_n  = sustain_n      # 연속 N회 ALERT 확인
        self.cooldown_s = cooldown_s     # 재기동 억제 시간
        self.hits       = 0
        self.last_wake  = 0.0
        self.history    = deque(maxlen=200)   # 최근 10초분 (20Hz)
        self.log_file   = None
        self.log_writer = None
        if log_path:
            self._open_log(log_path)

    def _open_log(self, path):
        os.makedirs(os.path.dirname(path) or '.', exist_ok=True)
        new = not os.path.exists(path)
        self.log_file   = open(path, 'a', newline='')
        self.log_writer = csv.writer(self.log_file)
        if new:
            self.log_writer.writerow(
                ['timestamp', 'esp_ms', 'state', 'total_kg',
                 'cog_x', 'cog_y', 'edge', 'vel',
                 'd_edge', 'd_w', 'tte', 'reason',
                 'FL', 'FR', 'RL', 'RR'])

    def feed(self, r: Reading):
        self.history.append(r)

        if self.log_writer:
            self.log_writer.writerow([
                datetime.now().isoformat(timespec='milliseconds'),
                r.ms, r.state, f"{r.total:.2f}",
                f"{r.cog_x:.1f}", f"{r.cog_y:.1f}",
                f"{r.edge:.3f}", f"{r.vel:.1f}",
                f"{r.d_edge:.3f}", f"{r.d_w:.1f}",
                f"{r.tte:.3f}", r.reason,
                *[f"{v:.2f}" for v in r.kg]])
            self.log_file.flush()

        if r.state == 'ALERT':
            self.hits += 1
        else:
            self.hits = max(0, self.hits - 1)

        now = time.time()
        if self.hits >= self.sustain_n and (now - self.last_wake) > self.cooldown_s:
            self.last_wake = now
            self.hits = 0
            self._trigger(r)
            return True
        return False

    def _trigger(self, r: Reading):
        print()
        print("=" * 62)
        print(f" TIER 1 인터럽트 발생  {datetime.now().strftime('%H:%M:%S')}")
        print(f"   총중량   {r.total:.2f} kg")
        print(f"   COG      ({r.cog_x:.1f}, {r.cog_y:.1f}) mm")
        print(f"   이탈도   {r.edge:.3f}  (변화율 {r.d_edge:+.2f}/s)")
        print(f"   체중변화 {r.d_w:+.1f} kg/s")
        print(f"   사유     {r.reason}")
        print(" -> Tier 2 비전 AI 기동")
        print("=" * 62)
        print()
        self.wake_event.set()

    def snapshot(self, seconds=3.0):
        """인터럽트 직전 N초 데이터 (Tier 2 링버퍼와 대응)"""
        now = time.time()
        return [x for x in self.history if now - x.recv_time <= seconds]
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

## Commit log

2026-09-17 Phase 0: v17 노트북을 모듈 구조로 재구성 + 재현 베이스라인
    - ymas/ 패키지로 분해: skeleton, preprocess(불변식), config, dataset,
    model(YmasNet, 1.50M state_dict), train(EMA/SWA/도메인균형), evaluate
    (precision 게이트 우선 임계값 선택), export(ONNX opset18)
    - scripts/train_baseline.py, scripts/export_onnx.py 진입점
    - configs/v17_baseline.yaml (v13 확정 하이퍼파라미터)
    - notebooks/colab_train.ipynb (git clone -> import ymas 실행기)
    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
2026-09-18 하드웨어/엣지/펌웨어/통합 자산을 래포로 정리
    인수인계 문서에서 '아직 못 본 실물'이던 Jetson·ESP32·CAD 자산을 구조화:
    - edge/ Tier 2 실시간 추론 (ymas_realtime_ir.py + C++ 브리지 + 캘리브/워치독/테스트)
    -> 전처리 함수·PMEAN/PSTD가 학습 코드(ymas/)와 동일함을 확인
    - integration/ Tier1<->Tier2 통합 (ymas_integrated.py[v13기준], tier1_receiver)
    -> ymas_integrated.py가 v13 기준이라 v17로 갱신 필요함을 README에 명시
    - firmware/ ESP32 Tier 1 펌웨어 (.ino, 80Hz/중앙값필터/3-Path/UDP)
    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
    [rail_bracket.stl, rail_loadcell_mount.scad, rail_pad.stl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]
2026-09-18 fix: scripts에서 직접 실행 시 ymas 임포트 실패 수정
    scripts/train_baseline.py, export_onnx.py 실행 시 파이썬 검색 경로에
    래포 루트가 없어 ModuleNotFoundError: No module named 'ymas' 발생.
    sys.path 에 래포 루트를 추가해 해결 (Colab에서 python scripts/... 직접 실행 대응).
2026-09-18 Phase 1: 오경보 해부 진단 스크립트 추가
    재현 베이스라인 체크포인트로 Val/Holdout 오경보를 도메인x클래스,
    피험자별, P(Fall) 분포로 분해. 하드 네거티브 재가중 전략을 데이터
    근거 위에서 세우기 위한 사전 진단 (넘겨짚기 방지).
2026-09-18 Phase 1: 진단에 Train 하드네거티브 후보 분석 추가
    증강 없는 Train non-Fall 샘플의 P(Fall) 분위/구간별 개수를 리포트.
    재가중 대상(낙상 닮은 정상/위험 자세)이 Train에 실제 존재하는지
    확인 -- 재가중이 헛방이 되지 않도록 사전 검증.
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2026-09-22 hardware: STL 재생성 + 밤부랩 H2D/PETG 출력 세팅 추가
    - 로드셀 하중 경로(rail_pad, rail_bracket) 및 전체 7종 STL을 최신 .scad에서 재생성
    (바운딩박스 치수 PRINT_GUIDE 표와 일치 검증 완료)
    - PRINT_GUIDE.md: 밤부랩 H2D + PETG 출력 세팅 섹션 추가
    (필라멘트 건조, Bambu Studio 프로파일, 배치 출력 노트)
    - 재료 결정을 PETG로 명시
    [rail_bracket.stl, rail_pad.stl, rail_ramp_seg0.stl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]
2026-09-22 hardware: H2D 베드 배치용 plate STL 3종 추가
    - make_plates.py: 개별 STL을 H2D 베드(350x320)에 묶는 생성기
    - plates/plate1_pads.stl rail_pad x4
    - plates/plate2_bracket_cradle.stl bracket x4 + cradle x4
    - plates/plate3_chock_ramp.stl chock x8 + ramp seg0/1/2 x2
    - 전 부품 PETG 전제, 겹침 0 / 베드 내 배치 검증 완료
    - plates/README.md + PRINT_GUIDE에 판별 인필 안내
    [plate1_pads.stl, plate2_bracket_cradle.stl, plate3_chock_ramp.stl]
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2026-09-22 hardware(scad): 패드 4점 지지 발 + 브래킷 두께 6->8mm
    - rail_pad: 하면 전면접촉 대신 네 모서리 12x2.5mm 지지 발 4점.
    바닥 요철/베드 워핑에도 3점 흔들림 없이 정의된 4점으로 지지 -> 영점 안정.
    볼트 카운터보어 영역 회피 배치. 4채널 모두 동일 상승이라 로드셀 상호 정합 유지.
    - rail_bracket: 6->8mm. 굽힘강성 약 2.4배(두께^3), 자유단 하중 전달부 처짐 보완.
    - rail_spec: FOOT_h/FOOT_d 파라미터 추가, DECK_Z 절대높이 주석 명시.
    [rail_loadcell_mount.scad, rail_spec.scad]
2026-09-22 hardware(scad): 크래들 V홈 파라메트릭화 + 램프 세그먼트 다웰 결합
    - wheel_cradle: V홈 개구폭을 바퀴 지름 기반으로 산출(현 공식), 측벽 로직을
    wall_w 로 명확화. wheel_thk/wheel_d 실측 강제 assert 추가(가정치 방지).
    echo 로 슬롯/측벽/V홈 진단 출력.
    - rail_ramp_segment: 접합면 다웰 핀(끝면)/구멍(시작면) 추가로 세그먼트 밀림 방지.
    d6 L8, 여유 0.35mm. seg0 시작/seg2 끝은 바깥이라 자동 생략.
    - 주: BRACKET_t 6->8 여파로 DECK_Z 87->89, RAMP_len/세그길이도 비례 증가(정상).
    [rail_ramp_segment.scad, wheel_cradle.scad]
2026-09-22 hardware: 개선 반영 STL/plate 전량 재생성 + plate3 배치 수정
    - 변경된 SCAD(패드 발, 브래킷 8mm, 크래들 파라메트릭, 램프 다웰)로 STL 7종 재생성
    - 램프가 다웰 핀으로 X방향 8mm 길어져 plate3 초과 -> chock 1열로 좁혀 해결
    - 3판 모두 베드(350x320) 내, 부품 겹침 0 검증 완료
    [plate1_pads.stl, plate2_bracket_cradle.stl, plate3_chock_ramp.stl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]
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2026-09-22 hardware: 어댑터 플레이트(80x80x12) 개정 + MCU 박스 복원
    - rail_bracket -> rail_adapter 로 개정: PDF 확정치 80x80x12.
    로드셀 자유단 4홀(19x15) 체결 + 레일 체결점을 ADP_OFFSET(임의 30mm)만큼
    이격해 바퀴 슬롯 관통 회피. 두께 12mm로 굽힘강성 확보.
    (오프셋 방향/거리는 실측 확정 필요 - MEASUREMENTS_TODO C)
    - mcu_enclosure.scad 신규 복원: base/lid, 80x60x30, ESP32 55x26x13 실측 반영,
    스탠드오프 4 + 뚜껑 M3 볼트/육각너트 트랩 + 케이블 인출구. 2-manifold 검증 완료.
    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
    [mcu_box_base.stl, mcu_box_lid.stl, mcu_enclosure.scad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]
2026-09-22 hardware: HX711 인클로저 복원 + 조립 뷰 정상화
    - hx711_enclosure.scad 신규: base/lid, 34x24x16(PDF 확정), 기판 25x15 안착 립,
    대각 M2 볼트/육각너트 트랩, 케이블 인출구 2. 2-manifold 검증 완료. 유닛당 1개=4개.
    - 인클로저 2종에 rail_system 호환 별칭(hx711_body/mcu_body) 추가
    -> rail_system.scad 전체 조립 뷰 렌더 복구(데크93/램프347/레일2100)
    - plate4 를 전자부 인클로저 판으로 확장(MCU 1세트 + HX711 4세트=10개), 겹침 0
    - README/plates README 갱신
    [hx711_box_base.stl, hx711_box_lid.stl, hx711_enclosure.scad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]
2026-09-22 hardware(plates): 재료별 폴더 분리 + 3MF 생성
    - plates/petg/ (하중경로: pad, adapter, cradle), plates/pla/ (비하중: chock,
    ramp, MCU/HX711 인클로저)로 분리 — PETG는 PETG끼리, PLA는 PLA끼리 출력
    - 각 plate STL + 3MF(Bambu Studio 네이티브) 둘 다 생성. 3MF 권장.
    - make_plates.py: 재료 매핑(MATERIAL) + 판별 재료 혼합 assert 차단,
    trimesh 로 멀티오브젝트 3MF export
    - 4판: plate_pads/plate_adapter_cradle(PETG), plate_chock_ramp/plate_enclosures(PLA)
    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
    [plate_adapter_cradle.3mf, plate_adapter_cradle.stl, plate_chock_ramp.3mf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]
2026-09-28 hardware(plates): 램프 제외 PLA 통합 판 추가 (chock+enclosures)
    - plate_chock_enclosures: 휠초크 8 + MCU(base+lid) + HX711(base x4+lid x4) = 18개
    램프를 지금 안 뽑을 때 한 판에 병합 출력용. 214x234mm, 겹침 0, 베드 내.
    - STL + 3MF 둘 다 생성, 3MF 18오브젝트/치수 검증
    - plates/README 에 통합 판 안내 추가(기존 chock_ramp/enclosures와 부품 겹침 명시)
    [plate_adapter_cradle.3mf, plate_chock_enclosures.3mf, plate_chock_enclosures.stl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]
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2026-09-30 fix(edge): 실시간 스크립트 경로 하드코딩 제거 + CUDA 프로바이더 폴백
    - /home/y-mas/ 하드코딩(계정 불일치) → edge/ 기준 상대경로로 자동 해석
    - YMAS_POSE_ONNX/YMAS_FALL_ONNX/YMAS_BED_JSON/YMAS_LOG_DIR 환경변수 override 지원
    - 모델 파일 부재 시 명확한 에러 메시지 후 종료(즉시 크래시 방지)
    - ONNX Runtime provider: CUDA 가능 시 사용, 없으면 CPU 폴백
    - 전처리 상수/소켓 경로/YOLO 파라미터 등 불변식은 변경 없음
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2026-09-30 fix(edge): StartLimitIntervalSec를 [Unit] 섹션으로 이동
    systemd 경고 'Unknown key StartLimitIntervalSec in [Service]' 수정.
    이 키는 [Unit] 섹션 소속이라 [Service]에 있으면 무시됨 → 재시작 제한 해제가
    실제로 적용되도록 위치 정정.
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2026-10-27 fix(poster): 설치 개념도 겹침 수정 (침대 제목 ↔ 카메라 박스 분리)
    침대 제목을 맨 위 단독 줄로 올리고, 적외선 ToF 카메라 녹색 박스를
    그 아래로 내려 겹침 제거. viewBox 높이 확대(340→390) 후 침대 상판·
    로드셀·COG·신호선·MCU 전체를 +42 재배치해 간격 확보.
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
